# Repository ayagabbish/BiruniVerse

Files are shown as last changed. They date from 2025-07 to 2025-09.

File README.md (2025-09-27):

<h1 align="center">BiruniVerse Team</h1>
<p align="center">
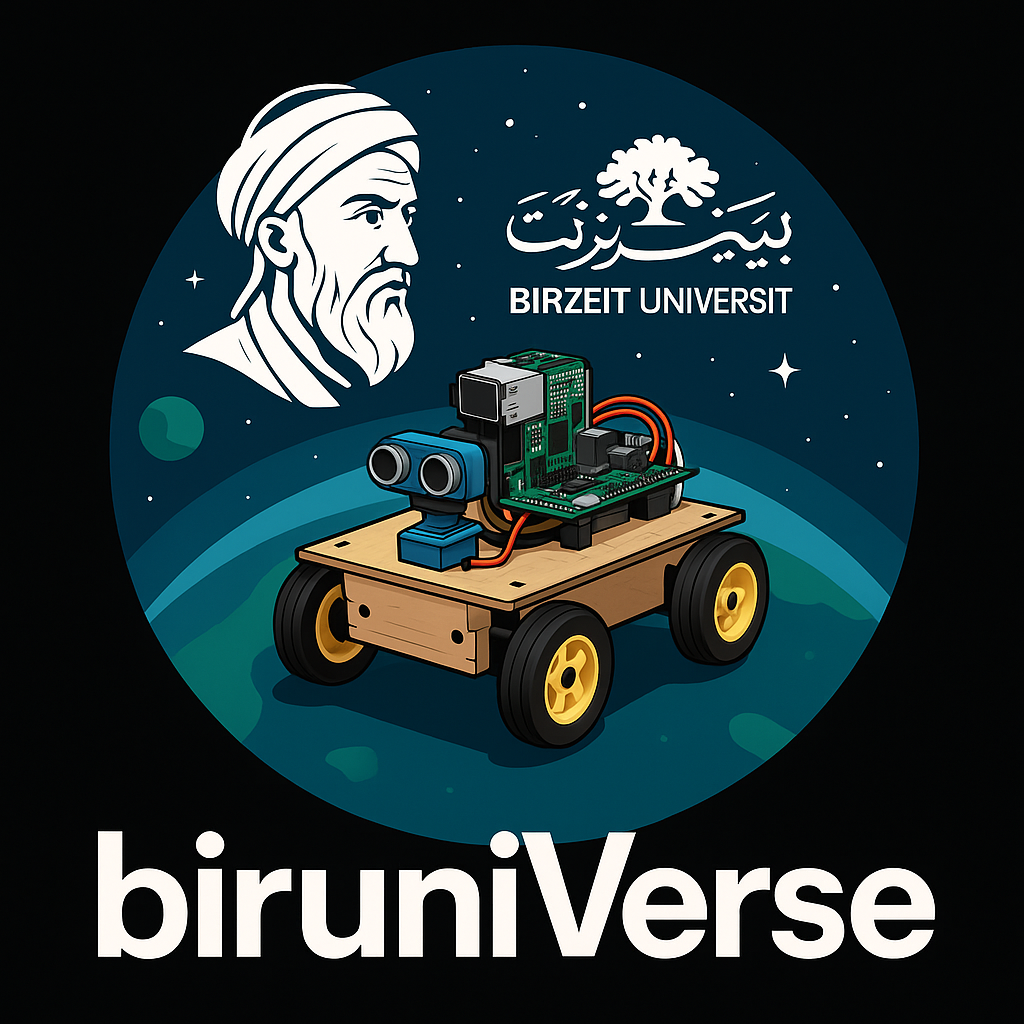
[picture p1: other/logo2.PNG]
BiruniVerse Logo
  

>  This repository documents the technical design, engineering processes, and development stages of our autonomous vehicle prototype. Built by three passionate engineering students, this robot is our gateway to the universe. United by creativity and curiosity, and supported by Birzeit University, we proudly present our journey in the WRO Future Engineers Challenge 2025.
## Content

* `t-photos` contains 2 photos of the team (an official one and one funny photo with all team members)
* `v-photos` contains 6 photos of the vehicle (from every side, from top and bottom)
* `video` contains the video.md file with the link to a video where driving demonstration exists
* `schemes` contains one or several schematic diagrams in form of JPEG, PNG or PDF of the electromechanical components illustrating all the elements (electronic components and motors) used in the vehicle and how they connect to each other.
* `src` contains code of control software for all components which were programmed to participate in the competition
* `models` is for the files for models used by 3D printers, laser cutting machines and CNC machines to produce the vehicle elements. If there is nothing to add to this location, the directory can be removed.
* `other` is for other files which can be used to understand how to prepare the vehicle for the competition. It may include documentation how to connect to a SBC/SBM and upload files there, datasets, hardware specifications, communication protocols descriptions etc. If there is nothing to add to this location, the directory can be removed.
# Table of Contents
- [Competition Overview](#competition-overview)
- [Who Are We?](#who-are-we)
- [Why BiruniVerse?](#why-biruniverse)
- [Understanding the Challenge](#understanding-the-challenge)
- [Robot Aims and Objectives](#robot-aims-and-objectives)
- [Hardware Design](#hardware-design)
  - [1. Chassis Plate](#1-chassis-plate)
  - [2. Wheels](#2-wheels)
    - [Front Wheels](#front-wheels)
    - [Rear Wheels](#rear-wheels)
  - [3. Steering Mechanism](#3-steering-mechanism)
  - [4. Gearbox](#4-gearbox)
  - [5. Controllers](#5controllers)
  - [6. Sensors](#6-sensors)
  - [7. Motors](#7-motors)
  - [8. Motor Drivers](#8-motor-drivers)
  - [9. Power](#9-power)
  - [10. Camera](#10-camera)
- [Strategies](#strategies)
  - [First Task: Navigation Without Traffic Signs](#first-task-navigation-without-traffic-signs)
  - [Second Task: Obstacle Avoidance](#second-task--obstacle-avoidance)
---

## Competition Overview

The World Robot Olympiad (WRO) challenges students to design and build autonomous robots.  
In the **Future Engineers** category, teams develop a self-driving car capable of navigating a randomized track using onboard sensors and control logic.  

The robot must be compact (**30 × 20 × 30 cm**) and operate fully without remote control.  
The goal is to replicate real-world autonomous driving, where the robot detects its environment, makes decisions, and completes laps reliably.  

Success is measured by both the robot’s performance on the track and the quality of the **engineering documentation** shared on GitHub, reflecting the full journey from design to competition-ready system.  

We chose to document our journey in the form of a story — step by step, from forming our team to building our final robot.  
Because in every line of code, every printed part, and every late-night fix, there is a story worth telling: a story of ideas turning into motion, and motion turning into achievement.  

##  Who Are We?

**spring 2025 – We came together.**  
Three students from different majors united with one goal: build a robot that goes beyond expectations.

-  **Alma Alkhader** – _Computer Engineer_  

-  **Aya Ghabbeish** – _Mechatronics Engineer_  

- **Sara Afifi** – _Mechanical Engineer_  

Together, we are **biruniVerse** — inspired by Birzeit and destined for the universe.

## Why BiruniVerse?

Our name **BiruniVerse** is built on two roots:  

- **Biruni** → A tribute to *Al-Biruni*, the great Muslim scholar and polymath, known for his groundbreaking contributions to science, astronomy, mathematics, and engineering. His curiosity and drive for discovery inspire us to push the limits of knowledge.  
- **Birzeituniversity (birUni)** → A proud reference to *Birzeit University*, our home, where this project was born. It connects our identity as students to a tradition of learning and innovation.  

The second part of our name, **Universe**, reflects our belief that through projects like these we are not only building robots — we are building the skills, imagination, and courage to reach for the universe itself.  

**BiruniVerse = Biruni + Birzeituni + Universe**  
A name that ties together heritage, identity, and aspiration.  

## Understanding the Challenge

Our journey began with the WRO 2025 Future Engineers rulebook, the document that defines every detail of the competition. Reading it gave us a clear picture of what the competition expected:  
a self-driving car that can complete laps on a randomized track, obey traffic rules with red and green pillars — all without human intervention.

After studying the rules, we joined training sessions at our university. There we met fellow participants, last year’s winners, coaches, and mentors. They encouraged us to ask questions, to experiment, and most importantly, to approach this as an engineering learning process, not just a race.

From there, we started exploring strategies and technical designs. We looked deeper into possible hardware parts that could be used, and we began asking specific questions to define our goals and shape our approach to solving the challenge.

##  Robot Aims and Objectives

- Detect obstacles using sensors and camera.  
- Avoid obstacles from the correct side.  
- Drive on its own without help.  
- Fix itself if it crashes or gets stuck.  
- Count laps and stop after finishing.  
- Stay inside size and hardware limits.

## Hardware Design

### 1. chassis Plate:

For the foundation of our robot, we chose a standard plastic chassis

<p align="center">
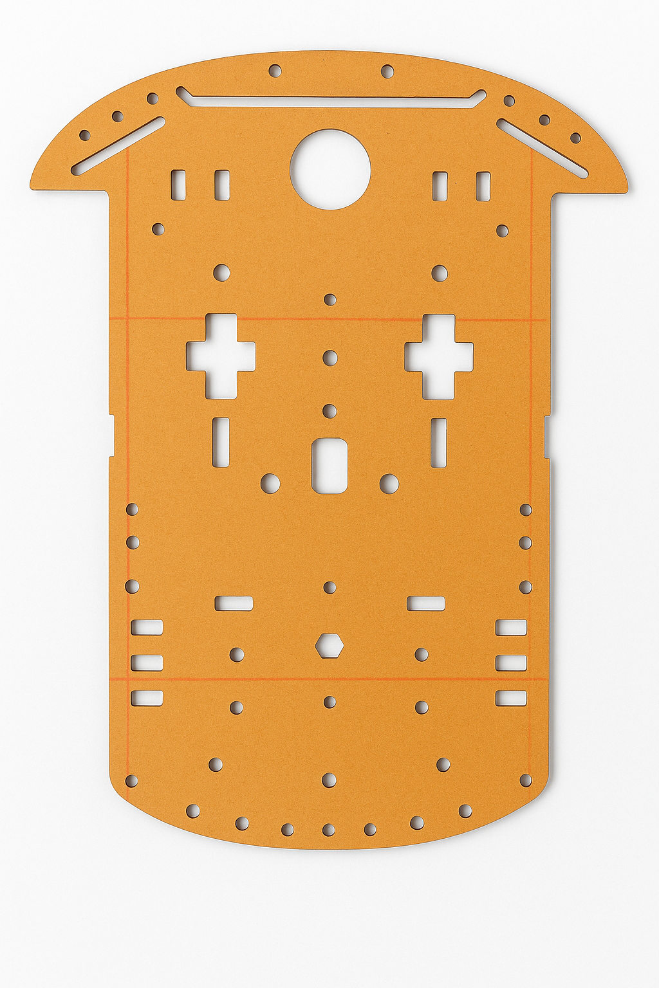
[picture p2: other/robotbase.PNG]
robotbase pic
  
</p>
The reason behind choosing this base was driven by simplicity and practicality, it offered a flat, stable surface with numerous mounting holes, which helped with arranging and securing components.

However, our structural requirements were not entirely satisfied by that base, so we had to modify it to fit our design by making new holes and gaps in the base to allow cleaner wire connection between the the upper controllers and the lower motors. Additionally, we made extra openings near the back to give the rear wheels enough clearance, and prevent them from hitting the base.

<p align="center">
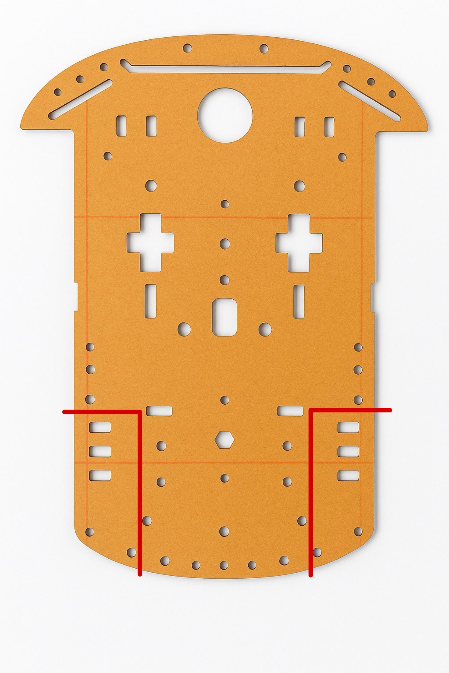
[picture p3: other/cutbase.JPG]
cutbase pic
  
</p>

This picture shows how the chassis was cut to fit the wheels properly.
for the cutting process, we used a **silverflo 928D tool soldering and cutting tool**, we relied on its heated tip and fine control to carefully shape the chassis.
<p align="center">
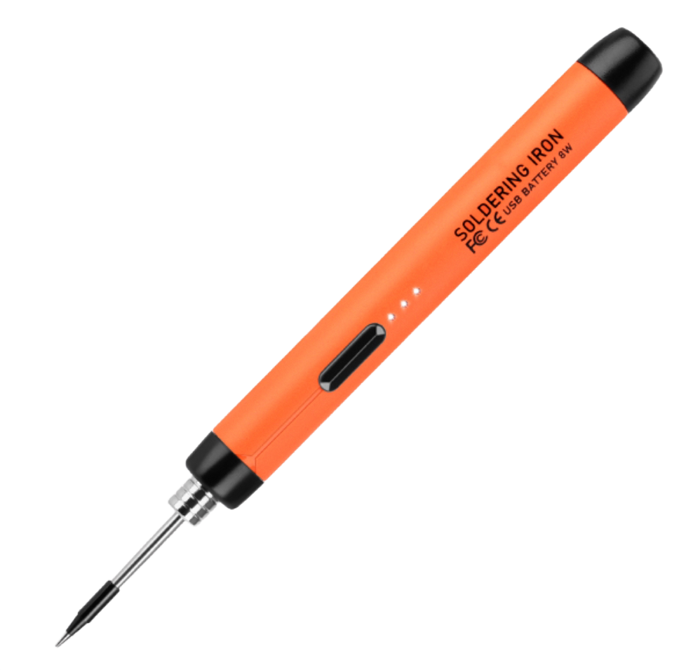
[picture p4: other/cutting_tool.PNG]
  
</p>

---

### 2. wheels:

#### Front Wheels

#### Starting Point – Store-Bought Wheels
We began with standard RC-style wheels that came with our chassis.  
These wheels consisted of:
- **Outer Tire**: black rubber with tread for grip.  
- **Plastic Hub**: inner white rim that holds the tire and connects to the axle.  

<p align="center">
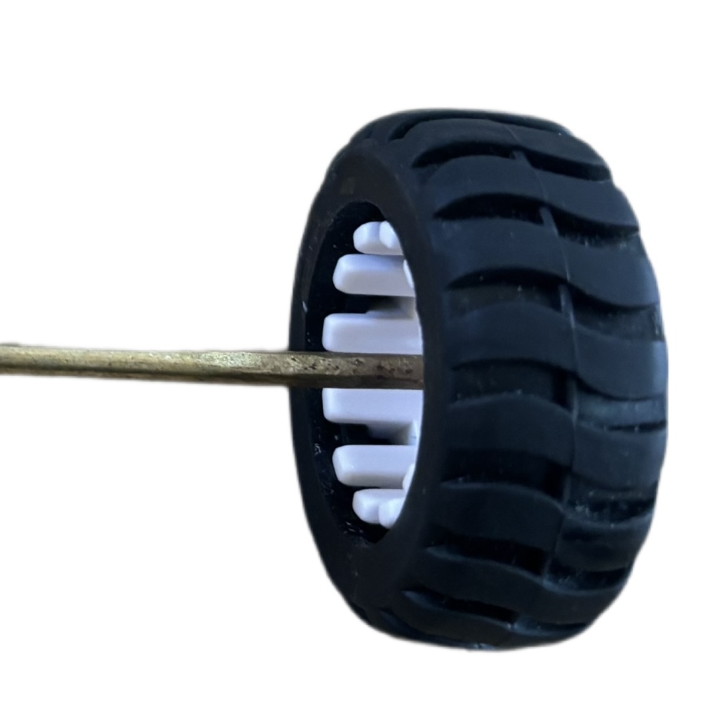
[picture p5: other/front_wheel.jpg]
frontwheelpic
  
</p>

#### Problem – Wobbling During Rotation
During testing, we noticed a **wobbling problem** in the wheels.  

The issue was caused by:
- Loose fit between the wheel hub and the axle.  
- Lack of a proper rotational support structure.  

This wobbling reduced **stability, steering precision, and vehicle speed**.
<p align="center">
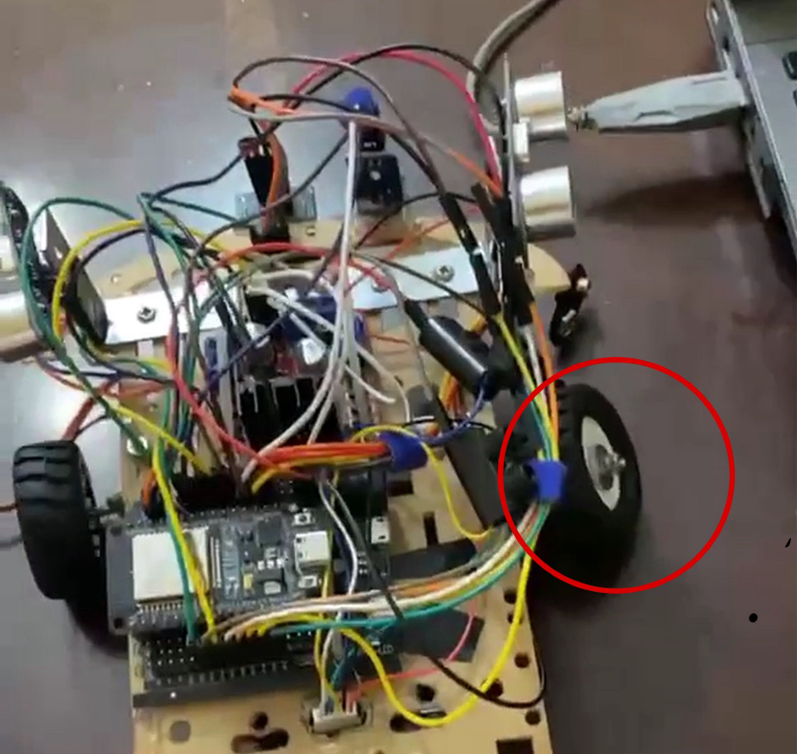
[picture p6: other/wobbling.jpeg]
wobblingwheelspic
  
</p>

#### Solution – Adding Bearings
To eliminate wobbling, we modified the wheels to include **ball bearings** (skateboard-style, model 608Z).

<p align="center">
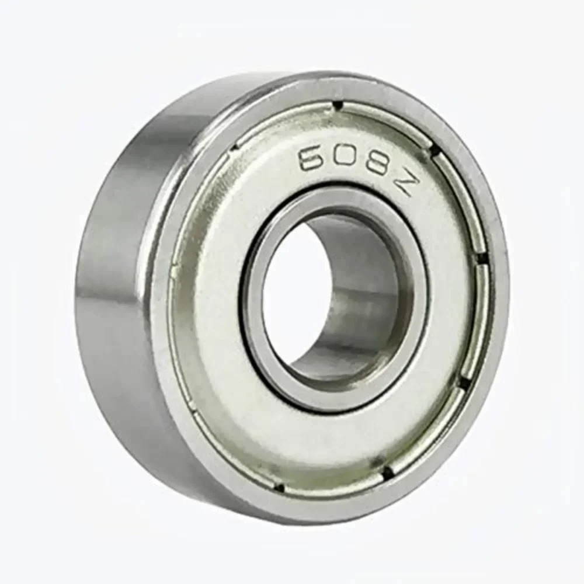
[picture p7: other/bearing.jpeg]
bearingspic
  
</p>

##### Why Bearings?
- Bearings allow the wheel to rotate smoothly around the axle.  
- They reduce friction, which increases efficiency.  
- They keep the wheel aligned and stable, preventing wobble.

### Front wheels assembly

1. **Outer Tire**  
   - Black part with tread made of rubber, providing grip on the track.  
   - Standard RC-style tire that slips over the wheel hub.  

2. **Wheel Hub (White Plastic Rim)**  
   - The inner white circular part that holds the tire.  
   - It was cut in some spots to fit the bearing.  

3. **Ball Bearing (608Z)**  
   - Standard skateboard/roller bearing.  
   - Allows the wheel to rotate smoothly around the axle with reduced friction.  

4. **Axle & Nuts Assembly**  
   - A metal threaded rod (axle) passes through the bearing.  
   - On the outside, nuts and washers fix the wheel in place to prevent wobbling.  
   - The threaded axle connects to the chassis, supported by mounts.
     
<p align="center">
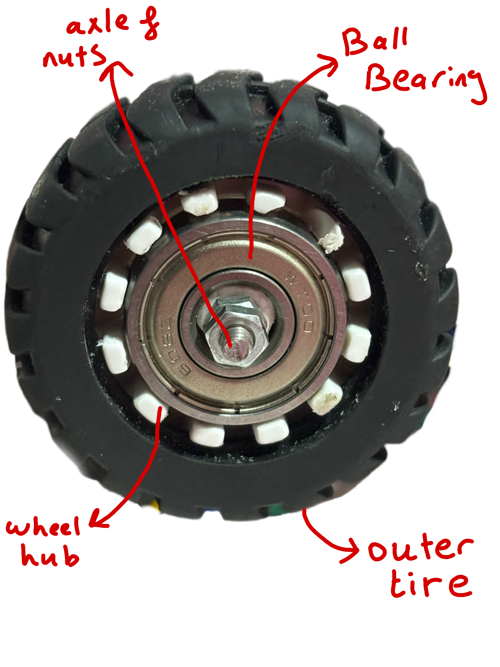
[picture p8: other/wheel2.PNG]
outsideviewoftires
  
</p>
*Outside view showing tire, hub, bearing, axle, and nuts.*  
<p align="center">
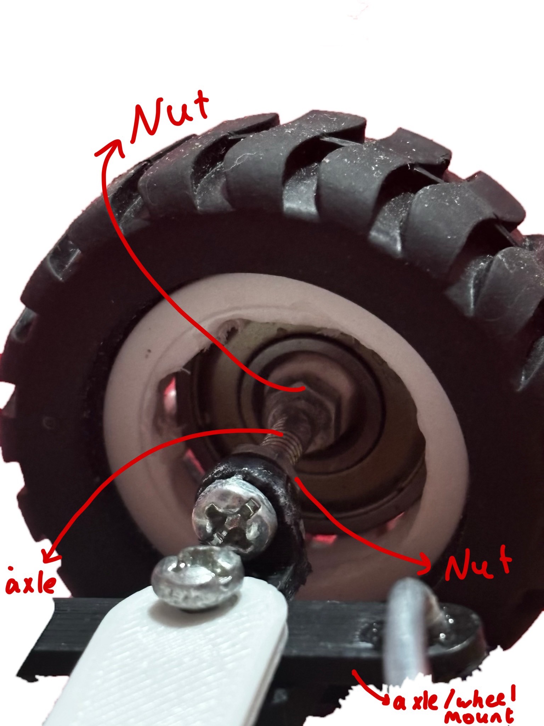
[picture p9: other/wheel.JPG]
insideviewoftires
  
</p>
*Inside view of the same assembly.*  

We used this same technique for **both front wheels**, ensuring stability and smooth steering.

---

#### Rear Wheels

For the rear wheels, we initially planned to use wheels similar to the front ones. However, after upgrading to a **stronger DC motor**, we faced an issue: the motor’s torque and size caused the motor to hit the ground.  

To solve this, we switched to **larger rear wheels**:  

<p align="center">
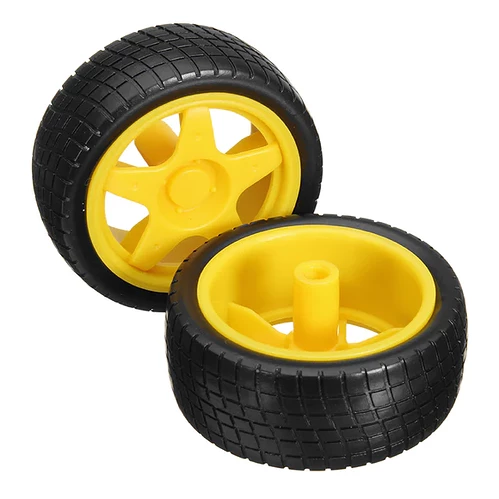
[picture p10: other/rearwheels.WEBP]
Rear Wheels
  
</p>  

our inspiration for Small Front wheels + Large Rear came from **Tractors**: 
This setup mimics heavy machinery like **Tractors**, which use **smaller front wheels** and **larger rear wheels**:  
- The **smaller front wheels** make steering easier and more precise.  
- The **larger rear wheels** provide the **power and stability**, supporting the motor’s torque and carrying most of the load.
  
  <p align="center">
  Rear Wheels
</p>  

---

### 3. Steering Mechanism:
for our steering meachanism we followed the idea in this video: https://youtu.be/ZdtPTUsrAA4?si=SmZMQu09OpZvmOV_

We decided to recreate the steering parts using SoliWorks, so we could 3D print them with strong plastic for durability.

Our robot uses a servo-based steering system inspired by real car steering (Ackermann principle). The mechanism ensures both front wheels turn together when the servo moves.

####  steering system components

| Name | Explanation | Picture |
|---|---|---|
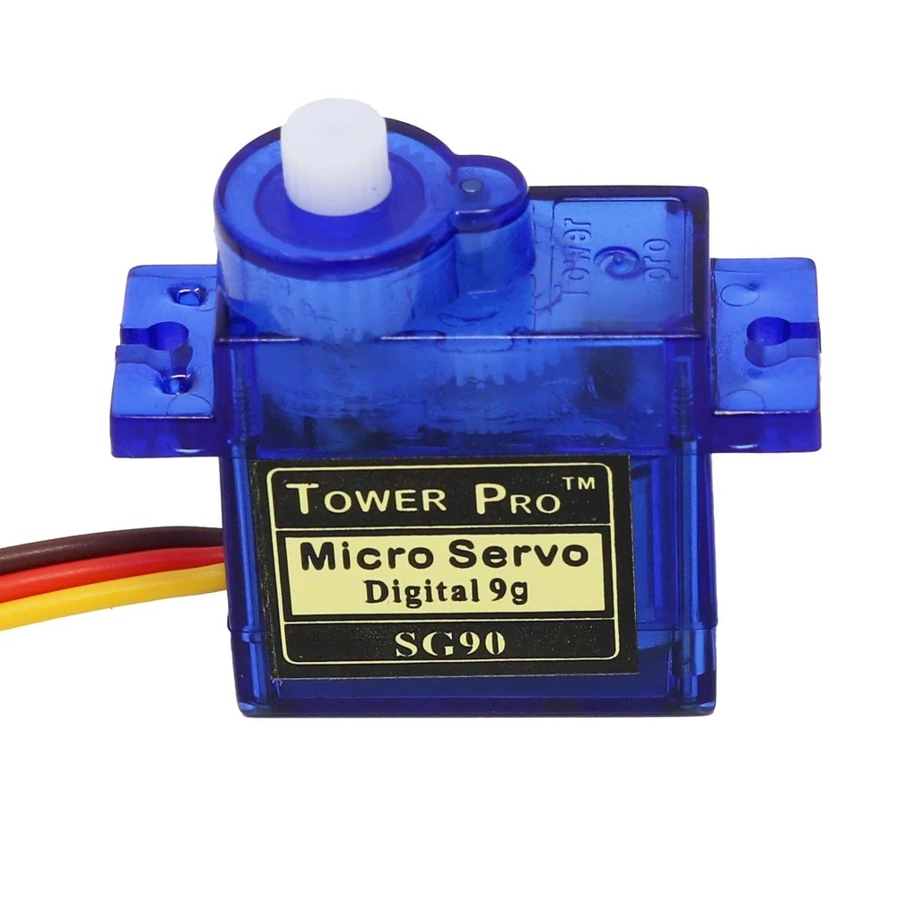
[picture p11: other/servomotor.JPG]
| **Servo Motor** | **Purpose:** The actuator that initiates steering. <br> **How it works:** The servo rotates a precise angle (controlled by the ESP32). |   |
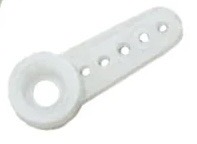
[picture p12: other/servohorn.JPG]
| **Servo Horn** | **Purpose:** The white plastic arm attached to the servo shaft. <br> **How it works:** When the servo rotates, the horn converts that into a small push–pull motion at its tip. <br> **Why needed:** Provides a lever arm so the servo’s rotation can be transferred into linear motion for the linkage rod. | |
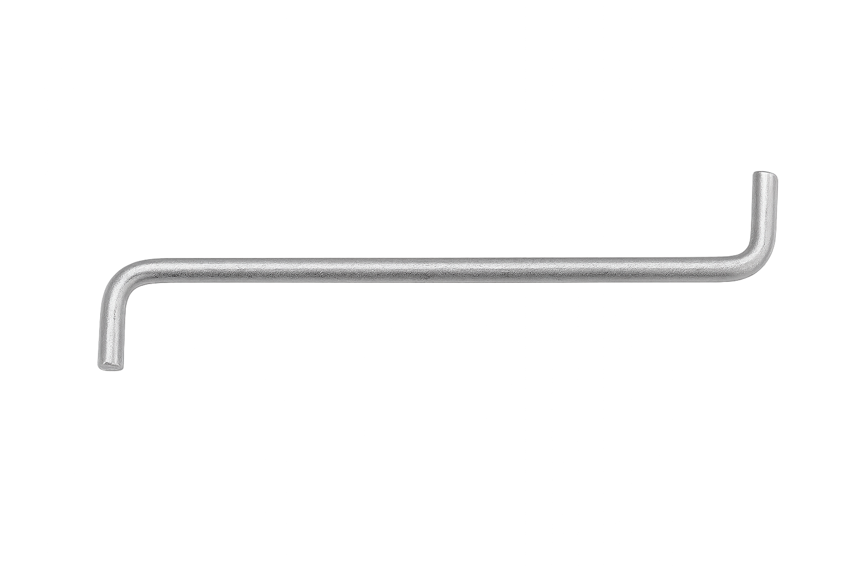
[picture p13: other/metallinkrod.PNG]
| **Metal Link Rod**  | **Purpose:** Connects the servo horn to the first steering knuckle. <br> **How it works:** Moves back and forth as the horn rotates, converting the servo’s rotation into reciprocating linear motion. <br> **Why needed:** Acts as the bridge between the servo and the steering system. Without it, the servo could not move the knuckle. |   |
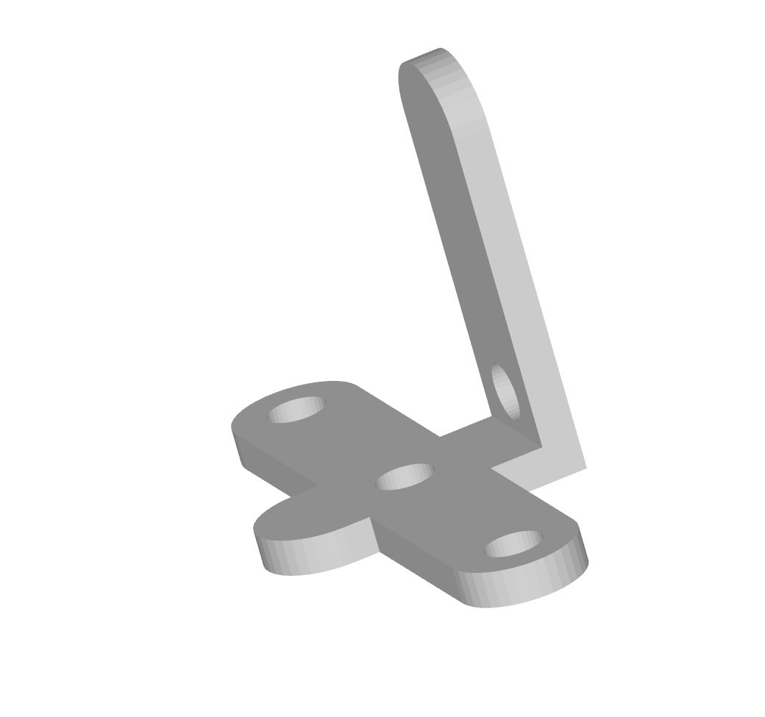
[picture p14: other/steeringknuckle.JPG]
| **Steering Knuckle**| **Purpose:** Holds the wheel axle and connects to both the linkage rod and the tie rod. <br> **How it works:** It pivots around a vertical screw fixed to the chassis. When the linkage rod pushes/pulls, the knuckle rotates, turning the wheel axle left or right. <br> **Why needed:** Essential for steering — it allows the wheel to turn while still being free to spin for forward/backward motion. |  |
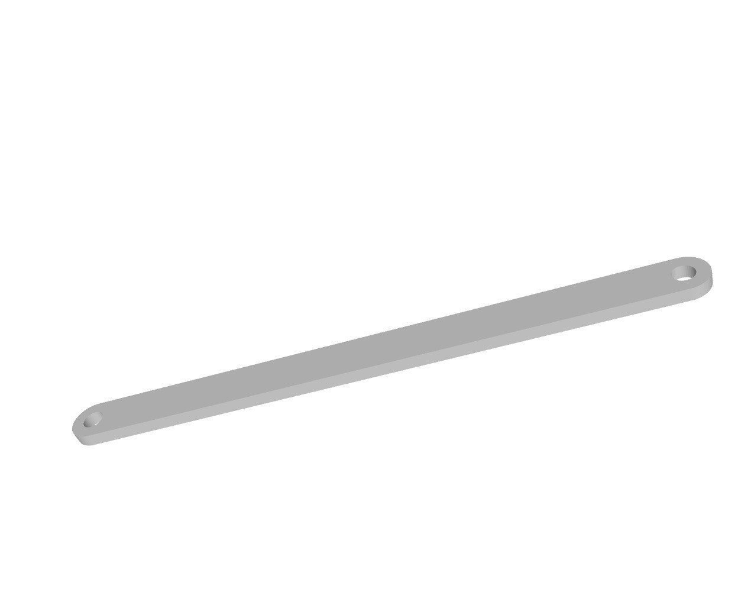
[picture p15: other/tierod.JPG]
| **Tie Rod** | **Purpose:** Connects the first steering knuckle to the second steering knuckle. <br> **How it works:** When the first knuckle pivots, the tie rod pushes or pulls the second knuckle so that both wheels turn together. <br> **Why needed:** Without it, only one wheel would steer, causing uneven turning and drag. The tie rod ensures synchronized steering. | |
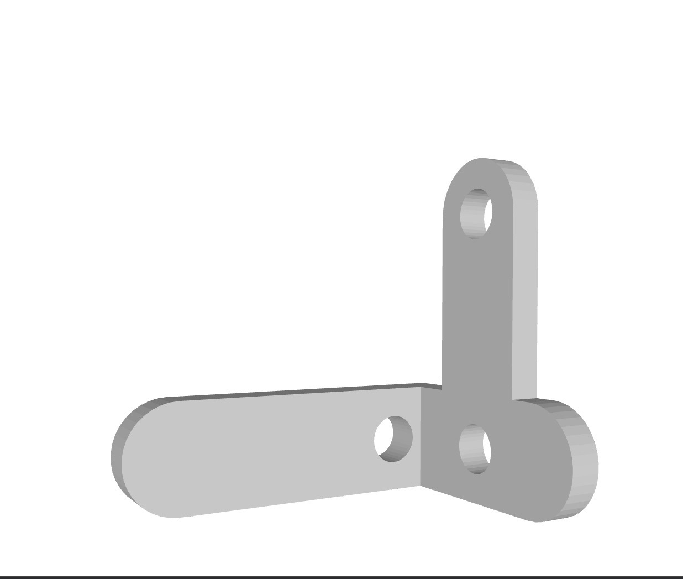
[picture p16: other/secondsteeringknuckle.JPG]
| **Second Knuckle**  | **Purpose:** Mirrors the motion of the first knuckle through the tie rod. <br> **How it works:** Pivots when pulled/pushed by the tie rod, turning the second wheel. <br> **Why needed:** Ensures the second wheel turns in harmony with the first, giving stable and accurate steering. | |
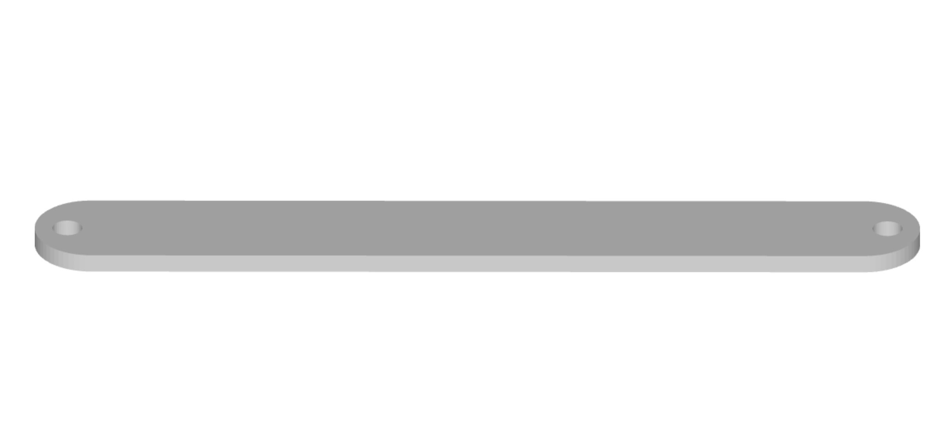
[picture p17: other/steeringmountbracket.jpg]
| **Steering Mount Bracket (x2)** | **Purpose:** Connects the steering knuckle to the chassis with a vertical screw. <br> **How it works:** Acts as the pivot base for the knuckle. <br> **Why needed:** Keeps the knuckle rigidly fixed in place, allows free pivoting around the screw without wobbling. |   |
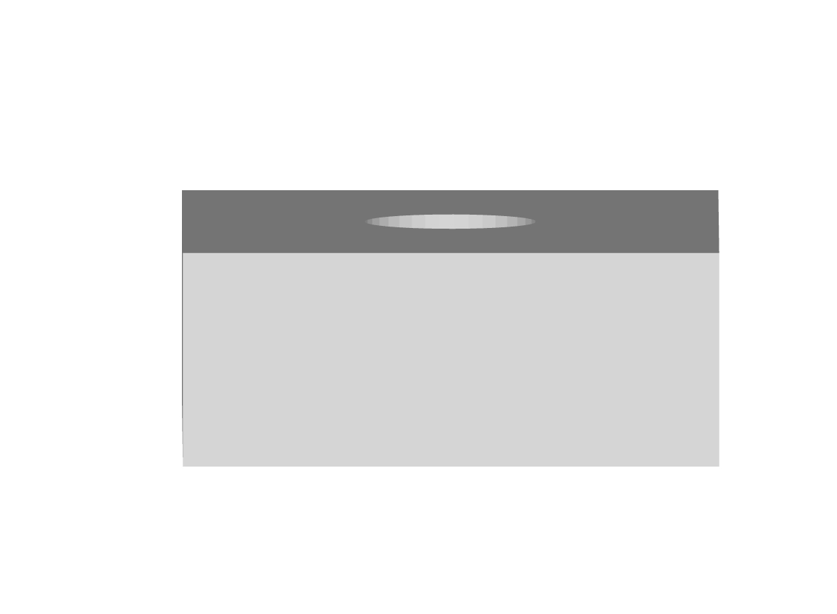
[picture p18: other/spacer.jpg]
| **Spacer Block (x2)** | **Purpose:** Provides the required vertical clearance between the mount bracket and the knuckle. <br> **How it works:** Sits between the mount bracket and the steering knuckle; the screw passes through it. <br> **Why needed:** Prevents the knuckle from rubbing against the mount bracket. Aligns the linkage rod and tie rod at the correct height for smooth steering geometry. |  |

---

### 4. Gearbox:

For our drivetrain, we built a **simple right-angle gearbox**. 
Before designing our own gearbox, we studied gears from a toy car.  
The images below show the original toy car gears and their measurements, which served as inspiration for our custom build, which we then adjusted its measurements to match our motor and build needs.

These are the toy car gears we used as inspiration for our gearbox design:

| | | |
|---|---|---|
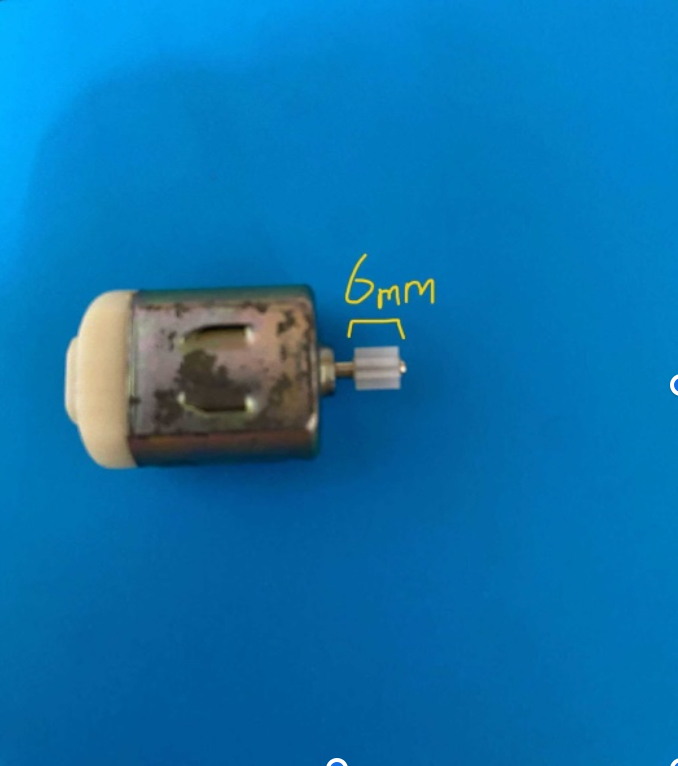
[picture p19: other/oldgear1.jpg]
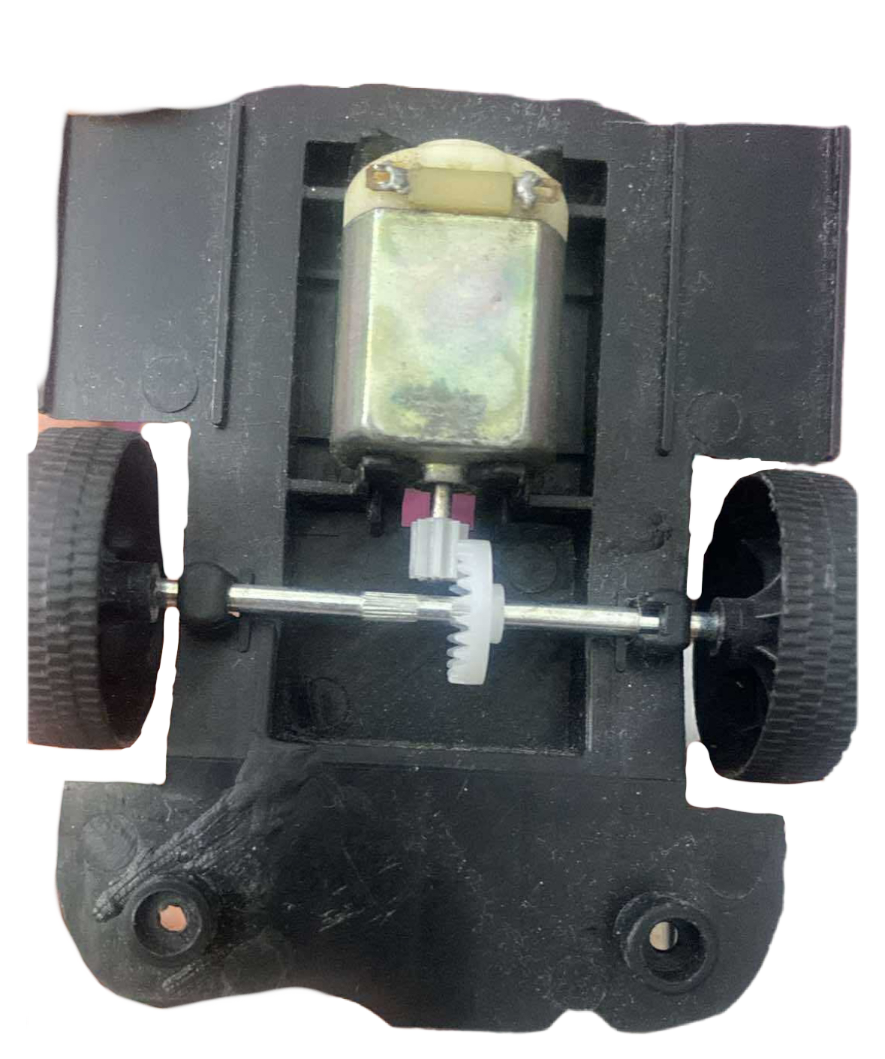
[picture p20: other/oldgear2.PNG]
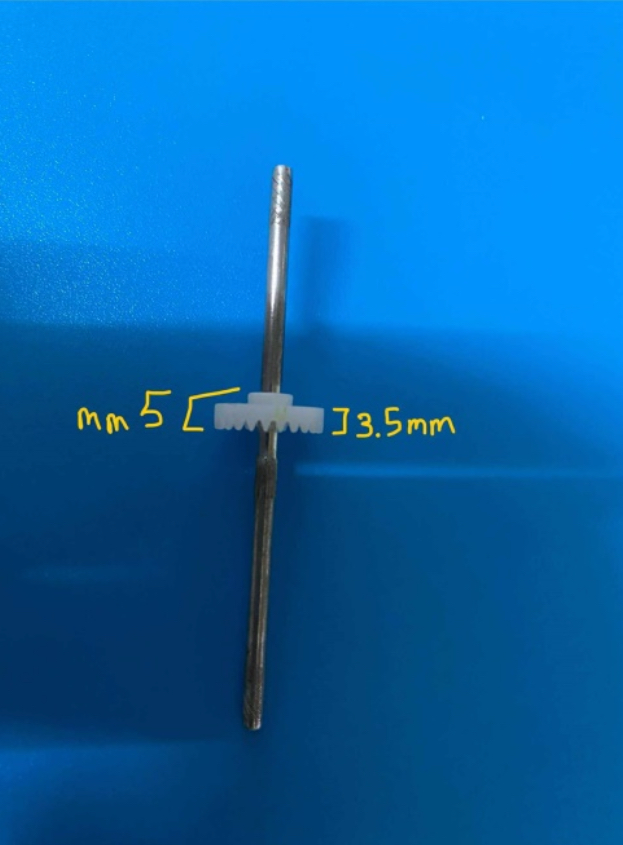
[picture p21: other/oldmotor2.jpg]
|  | |  |

#### Small Gear Component
- Length: **6 mm**  
- Gear teeth thickness: **3.2 mm** (but we required a larger outer diameter)  
- Motor mount diameter: **~3 mm** → the gear was hollowed out to fit this inner diameter.  
- Teeth count: **8 teeth**  
- Larger gear: **24 teeth**  
- Ratio: **1:3**  
- Special feature: the motor shaft is **D-shaped**, so the gear’s inner hole was designed with a matching **D-shaped cut** (not circular) to fit securely.

<p align="center">
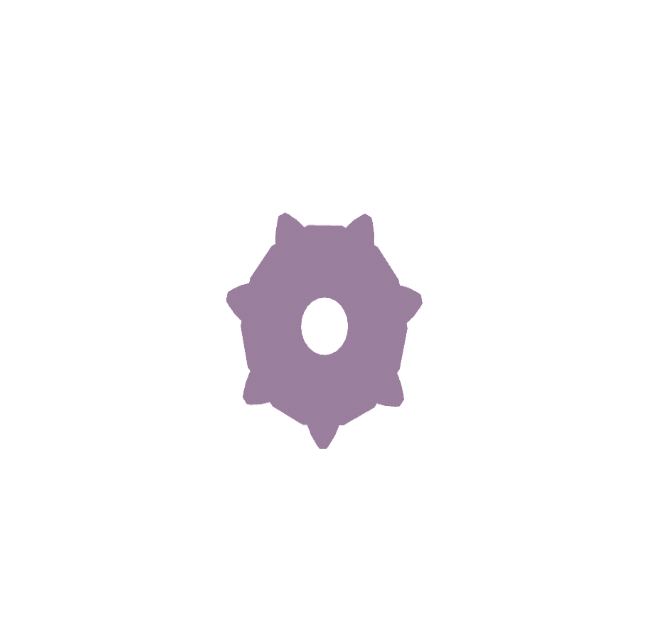
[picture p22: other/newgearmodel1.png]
  
</p>

#### Large Gear Component
- Teeth count: **24 teeth**  
- Pitch diameter: **7.2 mm** (original design)  
- Outer diameter: **≤ 10 mm**  
- Inner hole: **3 mm circular cutout** (for mounting)  
- Thickness: *(as per final design — adjusted for stability)*

<p align="center">
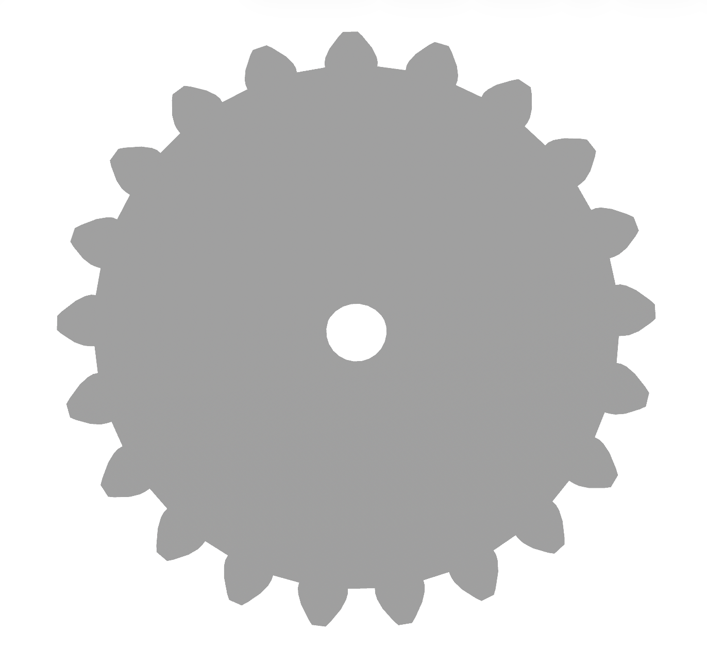
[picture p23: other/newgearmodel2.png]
  
</p>

final setup :
<p align="center">
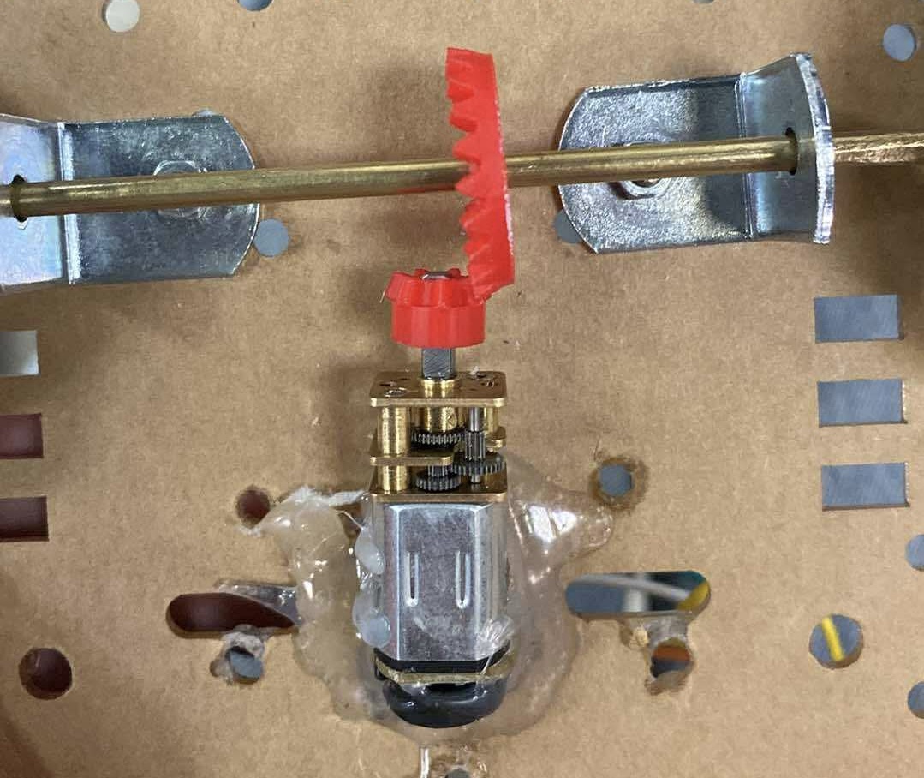
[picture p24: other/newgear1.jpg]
  
</p>
These picture were taken before replacing the DC motor.
These specifications guided the CAD modeling of the gears and ensured they were compatible with both our motor shaft and the required torque transfer for the robot.

---

### 5.controllers

The microcontroller is the **brain of the robot**, so our main priority was choosing the best one to do the job while also being cost-effective.

- Our first option was the **Arduino Nano 33 BLE Sense Rev2**, which supports machine learning models and is affordable.  
  However, we couldn’t find it locally in Palestine, so we decided to replace it with a **Raspberry Pi**.

- When comparing Raspberry Pi versions, we eliminated the 5th version because of **power limitations**.  
  The 4th version had better internet resources, making it easier to learn, but introduced new challenges:  
  the motors and sensors required different voltages than the Raspberry Pi. Using multiple voltage regulators seemed risky.

- To solve this, we decided on a **hybrid approach**:  
  - Use an **ESP32** connected to the **H-bridge** to handle motors and sensors, ensuring stable voltage regulation.  
  - Use the **Raspberry Pi 4** exclusively for **object detection**, reducing its workload and improving efficiency.

This combination allowed us to balance cost, availability, and performance while ensuring smooth operation of both control and perception tasks.

#### Raspberry Pi 4
<p align="center">
  Raspberry Pi 4
</p>

- **Processor**: 1.5GHz 64-bit quad-core  
- **RAM**: 8GB LPDDR4  
- **SD card**: 32GB 
- **Ports**: 2 USB 3.0 ports, 2 USB 2.0 ports
- **Operation Voltage** : 5.1V at 3A
- **Dimensions** : 85mm x 56mm x 17mm
- **Connectivity**:  
  - Dual-band Wi-Fi  
  - Bluetooth 5.0  
  - Gigabit Ethernet  
  - USB 3.0

***Purpose*** : The purpose of using the Raspberry Pi 4 was to connect a camera that provides visual input to the system. This input is then processed using machine learning, including image classification and recognition. Moreover, these methods guide the robot car to determine the turning direction based on live information and observations. In addition, the system can make decisions on the spot in a changing environment.

***Selection reason*** : As for the reason for choosing the Raspberry Pi 4, it is due to its easier-to-provide power source and lower power consumption. It is also more compatible when coding and using libraries. and lastly, its accessories are more affordable, and it generates less heat compared to the Raspberry Pi 5.

#### ESP32
<p align="center">
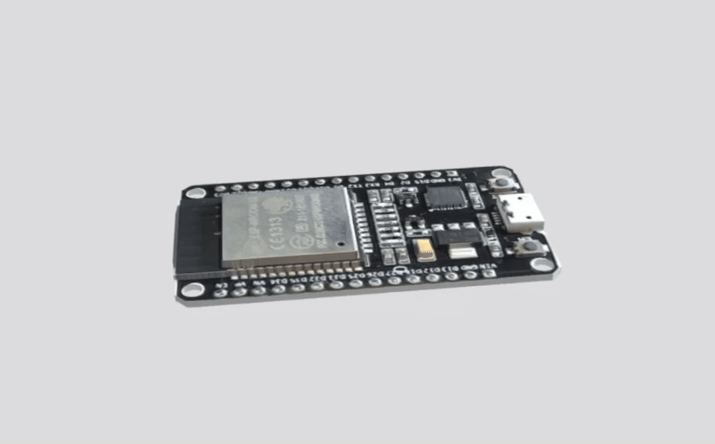
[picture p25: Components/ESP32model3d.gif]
Raspberry Pi 4
  
</p>

***Purpose*** : its to connect the rest of the robots components, sensors and motors, to ensure their best performance, we programmed the microcontroller using C++, It connects to the Raspberry Pi, which handles image recognition. Based on camera input (red or green obstacle), the Raspberry Pi sends commands to the ESP32, which then executes movement based on the code the esp32 runs, through the connected hardware.

***Selection reason*** : The ESP32 has many captivating and suitable features for our project, it has processing power of Dual-core 32-bit Xtensa CPU, up to 240 MHz, it has both Wi-Fi and Bluetooth (Classic + BLE) built-in, enough memory (520KB) to handle our code and execute it smoothly, has PWM On most GPIOs, its more cost effective, and it has more advanced features.

#### ESP32 Expansion Board
<p align="center">
<picture>
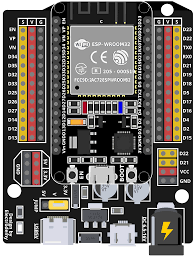
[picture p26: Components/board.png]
ESP32 Expansion Board
  
</picture>
</p>

- **Microcontroller**: ESP32 (dual-core, 240 MHz)  
- **Connectivity**: Wi-Fi + Bluetooth  
- **Operating Voltage**: 3.3V  
- **Programming**: Arduino IDE or MicroPython  
- **USB**: For power and programming (usually Micro-USB)  

***Purpose*** : Acts as the main controller for connecting sensors, processing inputs, and controlling outputs such as LEDs and motors.  

***Selection reason*** : Supports wireless communication, IoT applications, and runs code directly (Arduino/MicroPython). Flexible, powerful, and easy to integrate.  

---

---
### 6. sensors
#### Ultrasonic Sensor
<p align="center">
<picture>
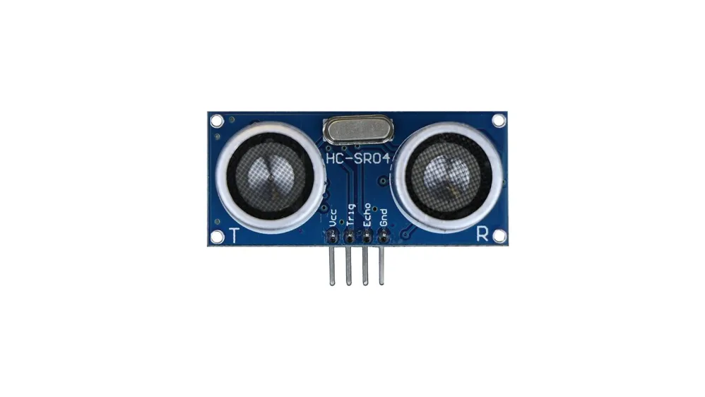
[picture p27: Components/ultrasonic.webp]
Ultrasonic Sensor
  
</picture>
</p>

**Model**: HC-SR04
**Voltage:** 5V DC  
**Current:** 15mA  
**Frequency:** 40Hz  
**Max Range:** 4m  
**Min Range:** 2cm  
**Measuring Angle:** 15°  
**Trigger Input:** 10µs TTL pulse  
**Echo Output:** TTL level signal (range proportional)  
**Dimensions:** 45 × 20 × 15 mm  

***Purpose*** : We have adopted a strategy that requires three ultrasonic sensors to be used effectively. Two sensors are placed on the sides, while the third is positioned at the front of the car. The side sensors are responsible for measuring the distance between the car and the walls on each side of the path. They continuously compare the two readings to determine the car’s position. When one of the side sensors detects a distance greater than the other by more than 2 meters, the system will determine that side as the turning direction of the path. As for the third sensor at the front, its main purpose is to measure the distance between the car and any obstacles, which will later be used to decide when the car should start turning at an angle to avoid collisions. It will also measure the distance between the walls of the track and the car, which will be useful—combined with our servomotor and camera in Task 2.

#### Infrared Sensor
<p align="center">
<picture>
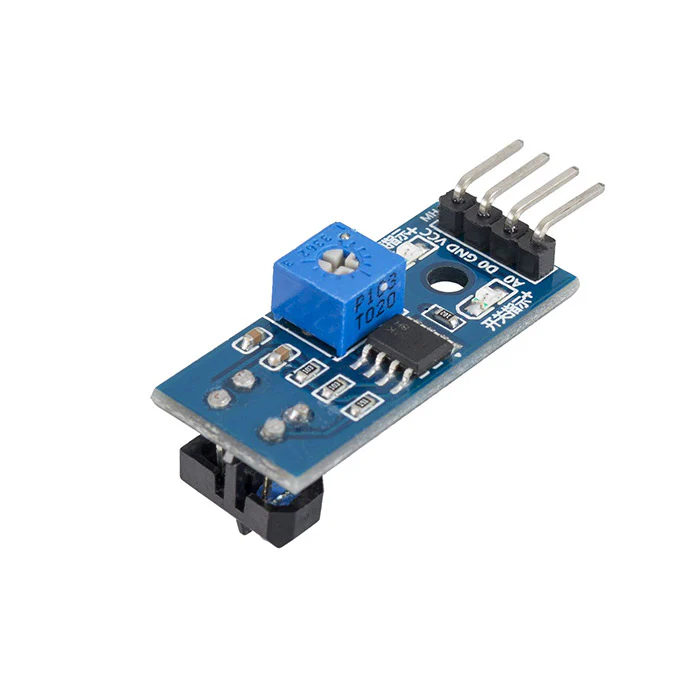
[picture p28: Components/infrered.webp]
Infrared Sensor
  
</picture>
</p>

- **Model**: TCRT5000  
- **Operating Voltage**: 3.3V – 5V  
- **Current Consumption**: ~18–20 mA  
- **Detection Range**: 2 mm – 15 mm (optimal within 2–10 mm)  
- **Output Signal**: Digital (HIGH/LOW) or Analog (depending on board version)  
- **Detection Type**: Reflective infrared (IR LED + phototransistor)  
- **Wavelength**: ~950 nm (IR emitter)  
- **Response Time**: <1 ms (fast switching)  
- **Adjustable Sensitivity**: Yes (via onboard potentiometer, if available)  
- **Indicator LEDs**: Power and output status  
- **Dimensions (module)**: ~3.2 cm × 1.4 cm (can vary by version)  

***Purpose*** : The purpose of this sensor is to detect short distances between the robot and its surroundings. While it may seem similar to the ultrasonic sensor, its main role is to provide an extra layer of safety to prevent collisions with obstacles or walls. It also helps the robot determine when to move backwards if needed.  

***Selection reason*** : It senses short distances more precisely than the ultrasonic sensor.  

#### Color Sensor
<p align="center">
<picture>
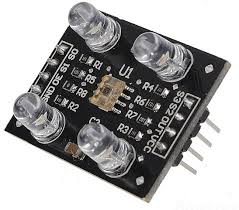
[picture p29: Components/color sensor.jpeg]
Color Sensor
  
</picture>
</p>

- **Model**: TCS3200 Color Sensor  
- **Operating Voltage**: 2.7V – 5.5V (typically 5V)  
- **Operating Current**: ~2.5 mA (average)  
- **Output Type**: Frequency (square wave) proportional to light intensity  
- **Sensing Element**: 8×8 array (64 photodiodes):  
  - 16 red filters  
  - 16 green filters  
  - 16 blue filters  
  - 16 clear (no filter)  
- **Selectable Output Frequency Scaling**: 100%, 20%, and 2%  
- **Measurement Range**: Full visible spectrum (RGB + clear)  
- **Response Time**: <100 ms typical  
- **Interface**: Digital output (no ADC needed)  
- **Detection Method**: Measures reflected light intensity of different colors  
- **Module Dimensions**: ~28 mm × 28 mm (may vary by version)  

***Purpose*** : Its main job is to detect either a green or orange line on the mat, which is used to count how many laps the robot car has completed. If it detects 12 orange lines, it means the car has finished 3 laps and should park (the mat has 4 orange lines at each corner, so 4 lines equal one lap). The color sensor also had another role in a different strategy: to determine the direction of the car (clockwise or counterclockwise). This was based on the color of the first line detected, which guided the system to track that color and decide turning direction, which was our initial stratege for counting laps before switching to a strategy that relies on sata from ultrasonic seneors.

***Selection reason*** : Provides reliable detection of specific colors, enabling lap counting and alternative navigation strategies.  

---

### 7. Motors:
#### Servo Motor
<p align="center">
<picture>
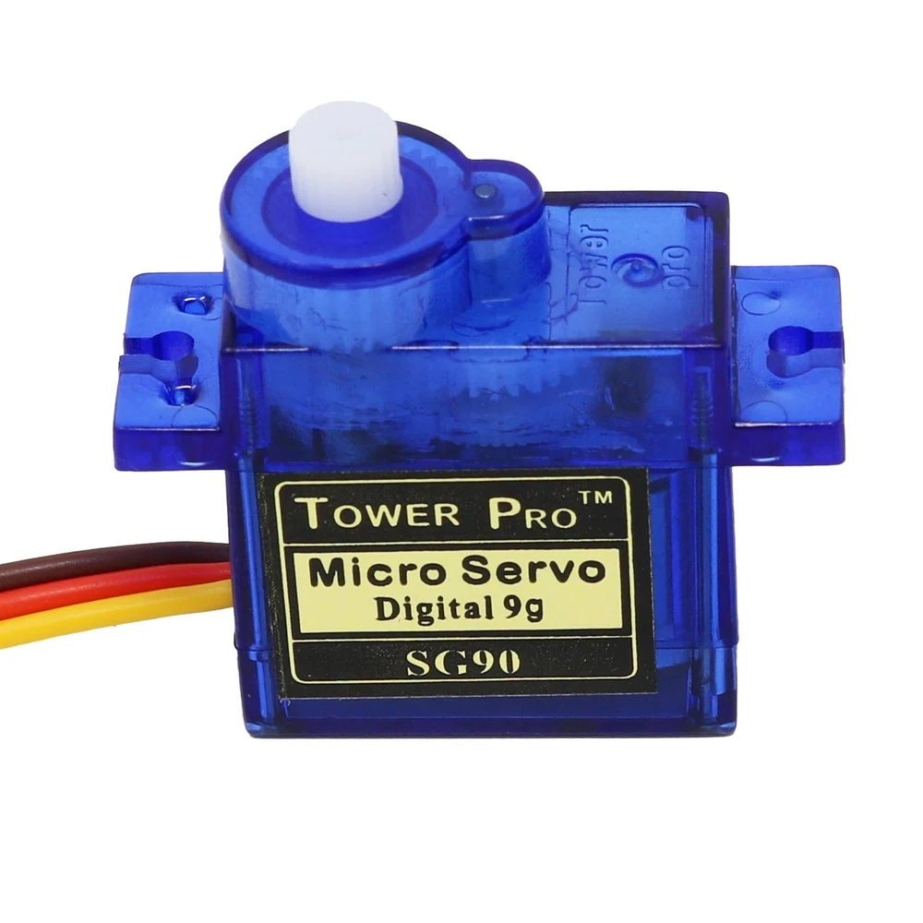
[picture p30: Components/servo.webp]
Servo Motor
  
</picture>
</p>

- **Model**:DCGM-N20-12V-EN-200RPM
- **Voltage**: 4.8V to 6V  
- **Operating Current**: ~100 mA to 250 mA (under load)  
- **Stall Torque**: 1.8 kg·cm at 4.8V  
- **Speed**: ~0.1 sec/60° at 4.8V  
- **Rotation Range**: 0° to ~180° (limited by internal stops)  
- **Control Signal**: PWM (50 Hz, 1–2 ms pulse width)  
- **Motor Type**: Brushed DC motor with control circuitry and feedback  
- **Weight**: ~9 g  
- **Dimensions**: 22.8 × 12.2 × 29.5 mm  
- **Gear Type**: Plastic gears  
- **Shaft Type**: Spline (21 teeth)  
- **Connector**: 3-pin (Signal, VCC, GND)  

***Purpose*** : Used in the robot car’s steering mechanism. In Task 2, it worked with the camera and Teachable Machine to avoid obstacles dynamically by adjusting angles gradually. In Task 1, it turned 90° at track edges with ultrasonic input to keep the car aligned.  

***Selection reason*** : Compact, affordable, easy to control, and accurate for 0°–180° rotation, making it ideal for steering.
#### DC Motor (JGA25-370)
<p align="center">
<picture>
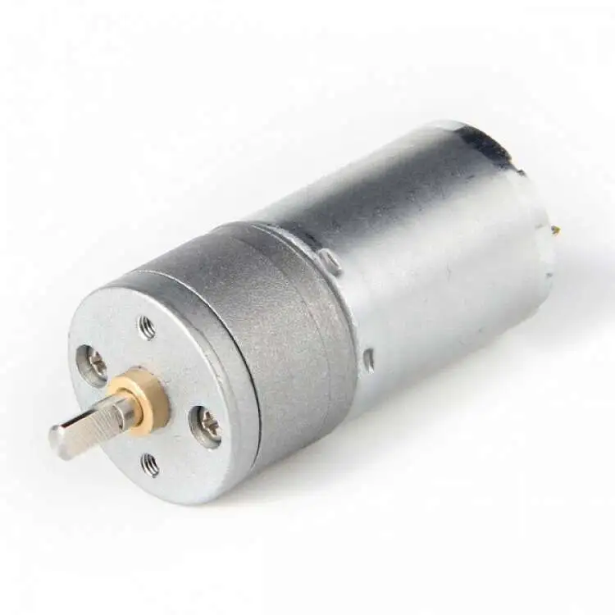
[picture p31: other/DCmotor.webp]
Servo Motor
  
</picture>
</p>

- **Model:** JGA25-370 DC Gear Motor  
- **Rated Voltage:** 6–12 V DC  
- **No-load Speed:** ~30–600 RPM (varies by gear ratio & supply voltage)  
- **No-load Current:** 70–150 mA  
- **Stall Torque:** 2–20 kg·cm (depending on gear ratio)  
- **Stall Current:** 1.5–2.5 A  
- **Gearbox:** 25 mm diameter, all-metal reduction gearbox  
- **Shaft Diameter:** 4 mm D-shaped output shaft  
- **Motor Type:** Brushed DC motor with integrated gearbox  
- **Rotation:** Reversible (via polarity swap)  
- **Dimensions:** ~25 mm (diameter) × 55–70 mm (length, depends on gear ratio)  
- **Mounting:** M3 threaded holes on gearbox face  

**Purpose**  
This motor is the muscle of our self-driving robot. With its built-in gearbox, it delivers the torque needed to move the car smoothly around the WRO track, even when friction or obstacles add resistance. Its cylindrical shape makes it easy to mount on a custom chassis without taking too much space.

**Selection Reason**  
We chose the JGA25-370 because it represents a balance between **strength and compactness**. Unlike the smaller XY-N20 motors, which are great for precision but limited in torque, this motor provides the raw pushing power we need for reliable forward motion and acceleration. With multiple gear ratio options, it allows us to tune for either **speed** or **endurance**, depending on the strategy. In short: this is the powerhouse that keeps our vehicle in motion.

### 8. Motor Drivers:

#### H-Bridge
<p align="center">
<picture>
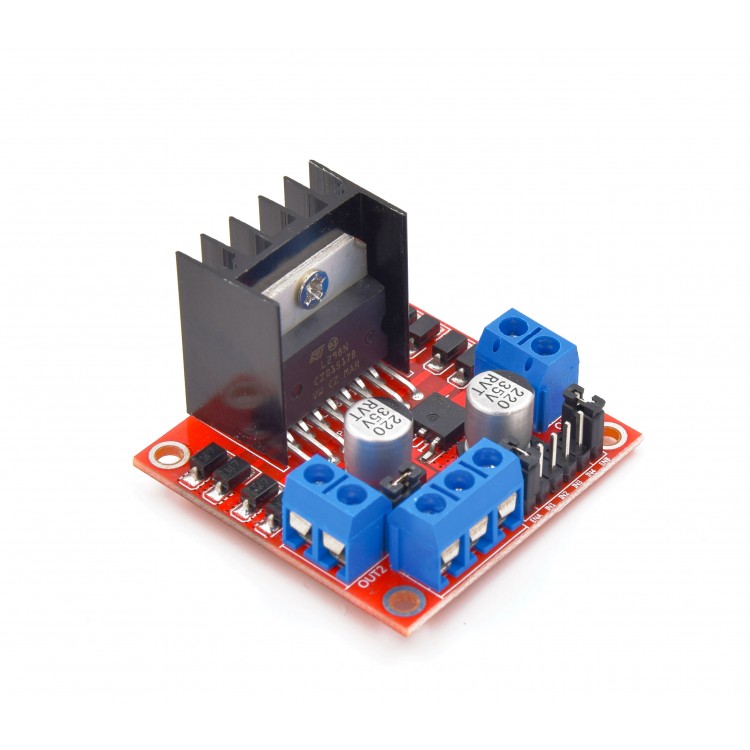
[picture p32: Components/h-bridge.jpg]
H-Bridge
  
</picture>
</p>

- **Voltage**: 5V to 35V  
- **Logic Voltage**: 5V  
- **Continuous Current**: 2A per channel  
- **Peak Current**: 3A per chann
- **Channels**: 2 (dual H-Bridge)  
- **Speed Control**: PWM (ENA/ENB pins)  
- **Direction Control**: IN1, IN2, IN3, IN4  
- **Protection**: Thermal shutdown, current limiting  
- **Flyback Diodes**: Included  

***Purpose*** : The ESP32 cannot directly reverse motor direction, but an H-Bridge enables this through simple digital HIGH/LOW signals. It also supports braking and freewheeling modes, offering finer control. It acts as a power driver, handling higher motor currents safely.  

***Selection reason*** : Without an H-Bridge, a DC motor can only spin one way. The H-Bridge makes motor control safe, programmable, and reliable.  
 
- **Model**: ESP32-WROOM-32 
- **Board**: NodeMCU-ESP32 (ESP32 DEVKITV1)  
- **Chip**: ESP32 (Dual-core Xtensa LX6, up to 240MHz)  
- **Wi-Fi**: 802.11 b/g/n (2.4GHz)  
- **Bluetooth**: v4.2 BR/EDR + BLE  
- **RAM**: 520KB SRAM  
- **Flash**: 4MB (or 16MB, depending on variant)  
- **GPIO Pins**: 38 (including ADC, DAC, UART, SPI, I2C)  
- **USB**: Micro-USB (for power/programming)  
- **Operating Voltage**: 3.3V
- **Dimensions** : 18mm x 25.5mm x 3.1mm

---

### 9. Power:

Our robot uses two different power sources to separate the load between the control electronics and the computing unit:

1. **9V Rechargeable Li-ion Battery (6600mAh)**
   - **Purpose:** Powers the **H-Bridge motor driver** and the **ESP32 microcontroller**.  
   - **Reasoning:** The ESP32 and H-Bridge require stable DC input for motor control and logic-level operations.  
   - **Advantage:** Keeps the motor driving system and the low-power controller on a dedicated supply, avoiding interference from the Raspberry Pi’s higher power draw.  
 <p align="center">
<picture>
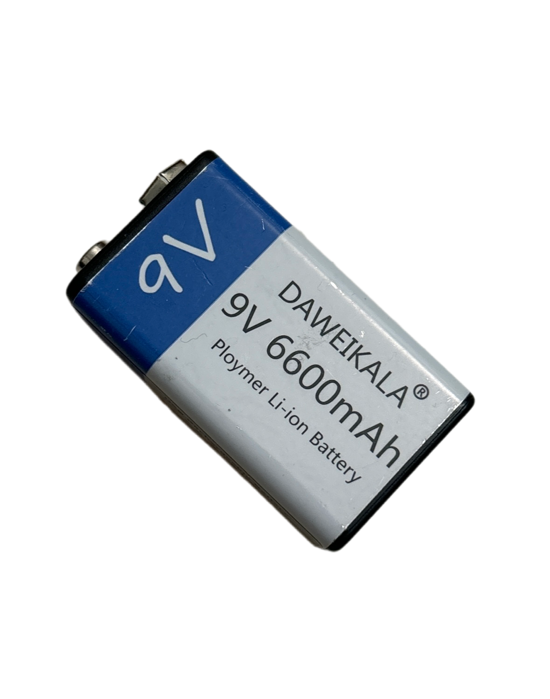
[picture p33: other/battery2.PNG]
  
</picture>
</p> 

2. **Billboard 10,000mAh Power Bank**
   - **Purpose:** Powers the **Raspberry Pi**.  
   - **Reasoning:** The Raspberry Pi demands higher current (via USB 5V) to handle computer vision and advanced processing tasks.  
   - **Advantage:** Provides long runtime with built-in overcharge protection and dual USB outputs, ensuring the Pi has a reliable and safe power source.  
<p align="center">
<picture>
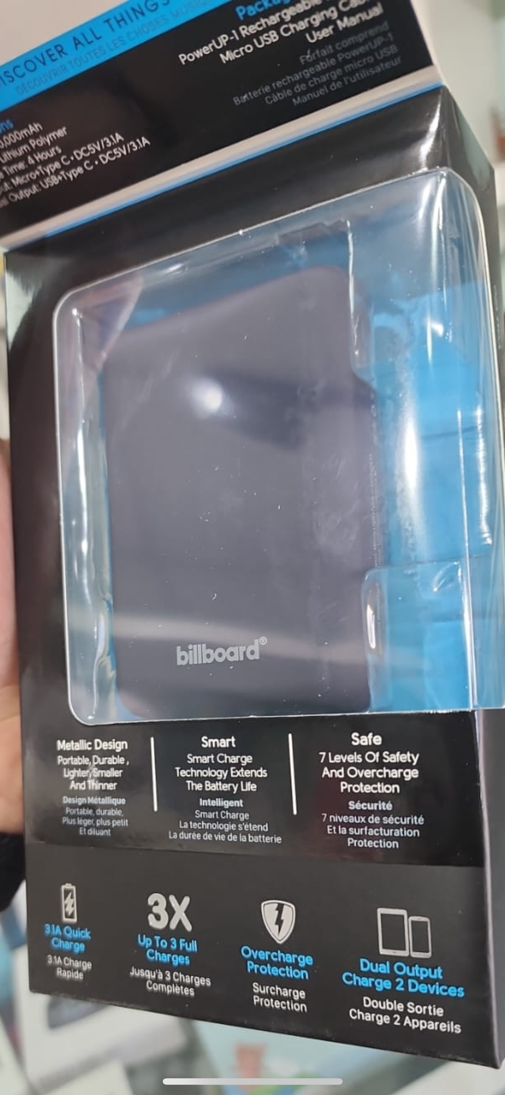
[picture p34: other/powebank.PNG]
  
</picture>
</p>
---

By splitting the power supply:
- The **motors and ESP32** receive dedicated current without fluctuations.  
- The **Raspberry Pi** operates independently, focused on vision and processing.  
This design ensures **stability, efficiency, and longer runtime** for the robot.

---

### 10. Camera:

For vision processing, we equipped the robot with the **Microsoft LifeCam Cinema** USB camera.

- **Resolution:** 720p HD  
- **Interface:** USB 2.0  
- **Purpose:** Provides real-time video input for the **Raspberry Pi**, which runs computer vision algorithms for obstacle detection and navigation.  
- **Reasoning:**  
  - Affordable and easily available.  
  - Compact size, suitable for mounting on the robot chassis.  
  - Reliable driver support on Linux/Raspberry Pi OS.

<p align="center">
<picture>
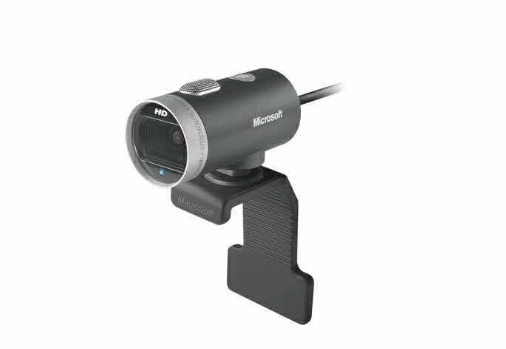
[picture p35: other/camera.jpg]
  
</picture>
</p>

----

## Strategies:

### First Task: Navigation Without Traffic Signs

For the first task of the WRO Future Engineers self-driving car challenge, our robot must navigate a track without traffic signs and complete **three laps**.  

1. **Wall-Following with Ultrasonic Sensors**
   - Two ultrasonic sensors are mounted on the left and right sides of the robot.  
   - On straight sections, the robot uses the sensor readings to maintain a centered position between the track walls.  
   - If one side is closer to the wall, the steering is adjusted to balance the readings and re-center the robot.

2. **Corner Detection**
   - When the robot approaches a corner, one ultrasonic sensor suddenly detects a **much larger distance** (open space).  
   - This change signals that a turn is required.  
   - On detecting a corner:
     - The robot briefly slows down or stops.  
     - The **servo motor** precisely steers the front wheels to execute the turn.  

3. **Lap Counting**
   - Each successful turn is counted as progress along the lap.  
   - After detecting **12 turns**, the robot concludes that **3 laps** have been completed.  
   - The robot then comes to a full stop.

**Key Points**
- **Ultrasonic sensors** ensure continuous wall detection and provide reliable corner identification.  
- **Servo steering** allows accurate maneuvering around corners.  
- **Turn-based lap counting** avoids the need for external markers and ensures consistent lap tracking.

---

### Second Task : Obstacle Avoidance

For the second task of the WRO Future Engineers self-driving car challenge, the robot must navigate a track while avoiding obstacles placed along the way.  

1. **Camera and Raspberry Pi (High-Level Control)**
   - A USB camera connected to the Raspberry Pi continuously captures frames.  
   - Each frame is processed by a **Teachable Machine Lite model** (`model.tflite` with `labels.txt`).  
   - Classification results determine the action:
     - **Red Block** → Raspberry Pi sends `L` (Left) via serial.  
     - **Green Block** → Raspberry Pi sends `R` (Right) via serial.  
     - **No Block / Other** → Raspberry Pi sends `F` (Forward).  
   - The Pi communicates commands to the **ESP32** through serial (TX/RX pins).  

2. **ESP32 and Actuators (Low-Level Control)**
   - The ESP32 interprets the commands from the Raspberry Pi.  
   - **L** → Servo motor steers the front wheels left.  
   - **R** → Servo motor steers the front wheels right.  
   - **F** → Motors continue forward using the H-Bridge driver.  

3. **Ultrasonic Sensors**
   - **Side ultrasonics**: Keep the robot centered on straights and detect corners (same logic as Task 1).  
   - **Front ultrasonic**: Measures distance directly ahead. If an obstacle is too close (e.g., < 15 cm), the robot stops, moves backwards, then avoids the obstacle in the correct way.  

4. **Lap Counting**
   - Just like in Task 1, each successful turn increments a counter.  
   - After **12 turns**, the robot concludes that 3 laps are complete and stops.  

**Key Points**
- **Dual-layer system**:  
  - Raspberry Pi handles **visual recognition and decision-making**.  
  - ESP32 + ultrasonic sensors handle **navigation, obstacle safety, and motor control**.  
- **Fail-safe operation**: If the camera fails to classify, the robot defaults to ultrasonic-based navigation.  
- **Stable execution**: The front ultrasonic ensures the robot never collides while reacting to visual cues.

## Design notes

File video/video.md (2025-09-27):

This is a demo video of our robot moving on the track.

<video src="./moving.mov" width="600" controls></video>

# Robot Demo Video

This is a demo video of our robot moving on the track.

## Local Video
<video src="./moving.mov" width="600" controls></video>
## Youtube Link 
[watch on youtube](https://youtube.com/shorts/H7jsI2t4uU8?si=0EMuis0wYFP-S493)

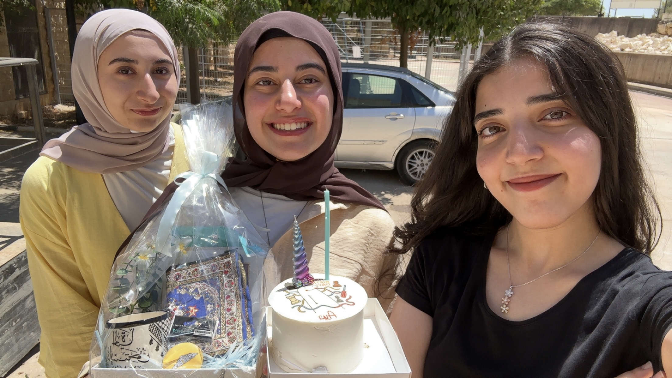
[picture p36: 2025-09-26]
t-photos/FunPicture.jpg

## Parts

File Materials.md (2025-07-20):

## Engineering Material
- Raspberri pi 4
- ESP-WROOM-32
- ESP32 expansion board
- H-bridge
- DC Mototr
- Servo Motor
- Infrared Sensor
- Color Sensor
- ultrasonics : we used 3 ultrasonics 2 on the sides and 1 in the front

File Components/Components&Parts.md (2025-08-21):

# Material
The Material we used to build our robot car
## Raspberry Pi 4
<p align="center">
  Raspberry Pi 4
</p>

- **Processor**: 1.5GHz 64-bit quad-core  
- **RAM**: 8GB LPDDR4  
- **SD card**: 32GB 
- **Ports**: 2 USB 3.0 ports, 2 USB 2.0 ports
- **Operation Voltage** : 5.1V at 3A
- **Dimensions** : 85mm x 56mm x 17mm
- **Connectivity**:  
  - Dual-band Wi-Fi  
  - Bluetooth 5.0  
  - Gigabit Ethernet  
  - USB 3.0

***Purpose*** : The purpose of using the Raspberry Pi 4 was to connect a camera that provides visual input to the system. This input is then processed using machine learning, including image classification and recognition. Moreover, these methods guide the robot car to determine the turning direction based on live information and observations. In addition, the system can make decisions on the spot in a changing environment.

***Selection reason*** : As for the reason for choosing the Raspberry Pi 4, it is due to its easier-to-provide power source and lower power consumption. It is also more compatible when coding and using libraries. and lastly, its accessories are more affordable, and it generates less heat compared to the Raspberry Pi 5.

## ESP32
<p align="center">
  Raspberry Pi 4
</p>

- **Model**: ESP32-WROOM-32 
- **Board**: NodeMCU-ESP32 (ESP32 DEVKITV1)  
- **Chip**: ESP32 (Dual-core Xtensa LX6, up to 240MHz)  
- **Wi-Fi**: 802.11 b/g/n (2.4GHz)  
- **Bluetooth**: v4.2 BR/EDR + BLE  
- **RAM**: 520KB SRAM  
- **Flash**: 4MB (or 16MB, depending on variant)  
- **GPIO Pins**: 38 (including ADC, DAC, UART, SPI, I2C)  
- **USB**: Micro-USB (for power/programming)  
- **Operating Voltage**: 3.3V
- **Dimensions** : 18mm x 25.5mm x 3.1mm

***Purpose*** : its to connect the rest of the robots components, sensors and motors, to ensure their best performance, we programmed the microcontroller using C++, It connects to the Raspberry Pi, which handles image recognition. Based on camera input (red or green obstacle), the Raspberry Pi sends commands to the ESP32, which then executes movement based on the code the esp32 runs, through the connected hardware.

***Selection reason*** : The ESP32 has many captivating and suitable features for our project, it has processing power of Dual-core 32-bit Xtensa CPU, up to 240 MHz, it has both Wi-Fi and Bluetooth (Classic + BLE) built-in, enough memory (520KB) to handle our code and execute it smoothly, has PWM On most GPIOs, its more cost effective, and it has more advanced features.

## Ultrasonic Sensor
<p align="center">
<picture>
  Ultrasonic Sensor
</picture>
</p>

**Model**: HC-SR04
**Voltage:** 5V DC  
**Current:** 15mA  
**Frequency:** 40Hz  
**Max Range:** 4m  
**Min Range:** 2cm  
**Measuring Angle:** 15°  
**Trigger Input:** 10µs TTL pulse  
**Echo Output:** TTL level signal (range proportional)  
**Dimensions:** 45 × 20 × 15 mm  

***Purpose*** : We have adopted a strategy that requires three ultrasonic sensors to be used effectively. Two sensors are placed on the sides, while the third is positioned at the front of the car. The side sensors are responsible for measuring the distance between the car and the walls on each side of the path. They continuously compare the two readings to determine the car’s position. When one of the side sensors detects a distance greater than the other by more than 2 meters, the system will determine that side as the turning direction of the path. As for the third sensor at the front, its main purpose is to measure the distance between the car and any obstacles, which will later be used to decide when the car should start turning at an angle to avoid collisions. It will also measure the distance between the walls of the track and the car, which will be useful—combined with our servomotor and camera in Task 2.

## Infrared Sensor
<p align="center">
<picture>
  Infrared Sensor
</picture>
</p>

- **Model**: TCRT5000  
- **Operating Voltage**: 3.3V – 5V  
- **Current Consumption**: ~18–20 mA  
- **Detection Range**: 2 mm – 15 mm (optimal within 2–10 mm)  
- **Output Signal**: Digital (HIGH/LOW) or Analog (depending on board version)  
- **Detection Type**: Reflective infrared (IR LED + phototransistor)  
- **Wavelength**: ~950 nm (IR emitter)  
- **Response Time**: <1 ms (fast switching)  
- **Adjustable Sensitivity**: Yes (via onboard potentiometer, if available)  
- **Indicator LEDs**: Power and output status  
- **Dimensions (module)**: ~3.2 cm × 1.4 cm (can vary by version)  

***Purpose*** : The purpose of this sensor is to detect short distances between the robot and its surroundings. While it may seem similar to the ultrasonic sensor, its main role is to provide an extra layer of safety to prevent collisions with obstacles or walls. It also helps the robot determine when to move backwards if needed.  

***Selection reason*** : It senses short distances more precisely than the ultrasonic sensor.  

## Color Sensor
<p align="center">
<picture>
  Color Sensor
</picture>
</p>

- **Model**: TCS3200 Color Sensor  
- **Operating Voltage**: 2.7V – 5.5V (typically 5V)  
- **Operating Current**: ~2.5 mA (average)  
- **Output Type**: Frequency (square wave) proportional to light intensity  
- **Sensing Element**: 8×8 array (64 photodiodes):  
  - 16 red filters  
  - 16 green filters  
  - 16 blue filters  
  - 16 clear (no filter)  
- **Selectable Output Frequency Scaling**: 100%, 20%, and 2%  
- **Measurement Range**: Full visible spectrum (RGB + clear)  
- **Response Time**: <100 ms typical  
- **Interface**: Digital output (no ADC needed)  
- **Detection Method**: Measures reflected light intensity of different colors  
- **Module Dimensions**: ~28 mm × 28 mm (may vary by version)  

***Purpose*** : Its main job is to detect either a green or orange line on the mat, which is used to count how many laps the robot car has completed. If it detects 12 orange lines, it means the car has finished 3 laps and should park (the mat has 4 orange lines at each corner, so 4 lines equal one lap). The color sensor also had another role in a different strategy: to determine the direction of the car (clockwise or counterclockwise). This was based on the color of the first line detected, which guided the system to track that color and decide turning direction.  

***Selection reason*** : Provides reliable detection of specific colors, enabling lap counting and alternative navigation strategies.  

---

## H-Bridge
<p align="center">
<picture>
  H-Bridge
</picture>
</p>

- **Voltage**: 5V to 35V  
- **Logic Voltage**: 5V  
- **Continuous Current**: 2A per channel  
- **Peak Current**: 3A per chann
- **Channels**: 2 (dual H-Bridge)  
- **Speed Control**: PWM (ENA/ENB pins)  
- **Direction Control**: IN1, IN2, IN3, IN4  
- **Protection**: Thermal shutdown, current limiting  
- **Flyback Diodes**: Included  

***Purpose*** : The ESP32 cannot directly reverse motor direction, but an H-Bridge enables this through simple digital HIGH/LOW signals. It also supports braking and freewheeling modes, offering finer control. It acts as a power driver, handling higher motor currents safely.  

***Selection reason*** : Without an H-Bridge, a DC motor can only spin one way. The H-Bridge makes motor control safe, programmable, and reliable.  

---

## DC Motor (XY-N20)
<p align="center">
<picture>
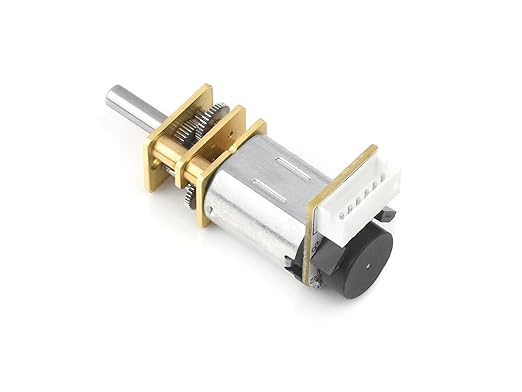
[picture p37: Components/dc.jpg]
XY-N20 DC Gear Motor
  
</picture>
</p>

- **Model**: XY-N20 DC Gear Motor with Magnetic (Hall) Encoder  
- **Rated Voltage**: 12 V DC  
- **No-load Speed**: ~200 RPM  
- **No-load Startup Voltage**: ~3 V (max)  
- **No-load Current**: ~0.1 A (max)  
- **Locked-rotor (Stall) Torque**: ≥ 1.2 kg·cm  
- **Locked-rotor (Stall) Current**: ≥ 1.1 A  
- **Encoder Type**: AB dual-phase incremental magnetic Hall encoder  
- **Encoder Resolution**: Basic 7 PPR × 150 gear ratio = ~1050 PPR  
- **Encoder Power Supply**: 3.3 V or 5 V (with internal pull-up)  
- **Response Frequency**: Up to ~100 kHz  
- **Gearbox**: All-metal, high-precision reduction gearbox  
- **Connector**: L-shaped 6-pin (for motor power and encoder signals)  
- **Rotation**: Reversible (via polarity swap)  

***Purpose*** : Provides both motion and precise feedback for the robot’s navigation. The built-in encoder enables accurate speed or position sensing, improving control over direction and obstacle avoidance.

***Selection Reason*** : Combines durable all-metal gearing with integrated encoder feedback. This enhances both reliability and accuracy, making it ideal for robotics applications needing lightweight yet precise actuators.

---

## Servo Motor
<p align="center">
<picture>
  Servo Motor
</picture>
</p>

- **Model**:DCGM-N20-12V-EN-200RPM
- **Voltage**: 4.8V to 6V  
- **Operating Current**: ~100 mA to 250 mA (under load)  
- **Stall Torque**: 1.8 kg·cm at 4.8V  
- **Speed**: ~0.1 sec/60° at 4.8V  
- **Rotation Range**: 0° to ~180° (limited by internal stops)  
- **Control Signal**: PWM (50 Hz, 1–2 ms pulse width)  
- **Motor Type**: Brushed DC motor with control circuitry and feedback  
- **Weight**: ~9 g  
- **Dimensions**: 22.8 × 12.2 × 29.5 mm  
- **Gear Type**: Plastic gears  
- **Shaft Type**: Spline (21 teeth)  
- **Connector**: 3-pin (Signal, VCC, GND)  

***Purpose*** : Used in the robot car’s steering mechanism. In Task 2, it worked with the camera and Teachable Machine to avoid obstacles dynamically by adjusting angles gradually. In Task 1, it turned 90° at track edges with ultrasonic input to keep the car aligned.  

***Selection reason*** : Compact, affordable, easy to control, and accurate for 0°–180° rotation, making it ideal for steering.  

---

## ESP32 Expansion Board
<p align="center">
<picture>
  ESP32 Expansion Board
</picture>
</p>

- **Microcontroller**: ESP32 (dual-core, 240 MHz)  
- **Connectivity**: Wi-Fi + Bluetooth  
- **Operating Voltage**: 3.3V  
- **Programming**: Arduino IDE or MicroPython  
- **USB**: For power and programming (usually Micro-USB)  

***Purpose*** : Acts as the main controller for connecting sensors, processing inputs, and controlling outputs such as LEDs and motors.  

***Selection reason*** : Supports wireless communication, IoT applications, and runs code directly (Arduino/MicroPython). Flexible, powerful, and easy to integrate.  

---

## Camera
<p align="center">
<picture>
  Camera
</picture>
</p>

***Specification*** : (to be filled)  

***Purpose*** : Provides real-time visual input for machine learning–based navigation and obstacle detection.  

***Selection reason*** : Essential for implementing image recognition and guiding the robot’s decision-making system.  

---

## Teachable Machine
<p align="center">
<picture>
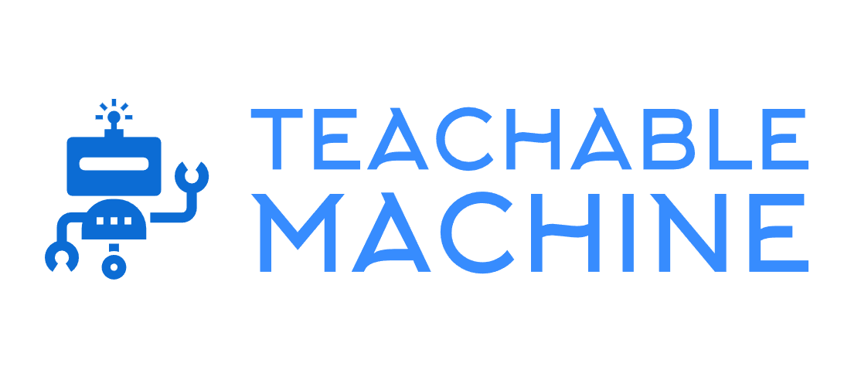
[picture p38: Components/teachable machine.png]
Teachable Machine
  
</picture>
</p>

***Purpose*** : Allowed the team to quickly train an image classification model without complex coding. The model was exported as TensorFlow Lite and deployed to the device for real-time object recognition, integrating machine learning into the robot’s decision-making system.  

***Selection reason*** : Simplified ML integration, reduced development time, and provided accessible tools for fast prototyping.

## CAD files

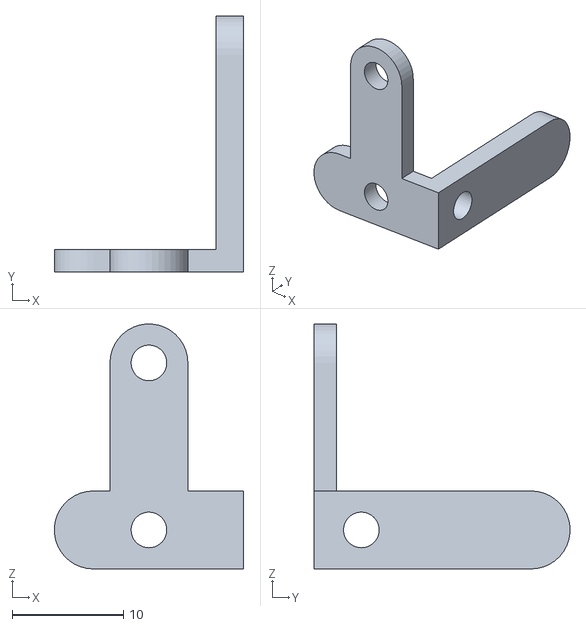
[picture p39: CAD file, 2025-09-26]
models/Part1better.STL
17.0 x 23.0 x 22.0

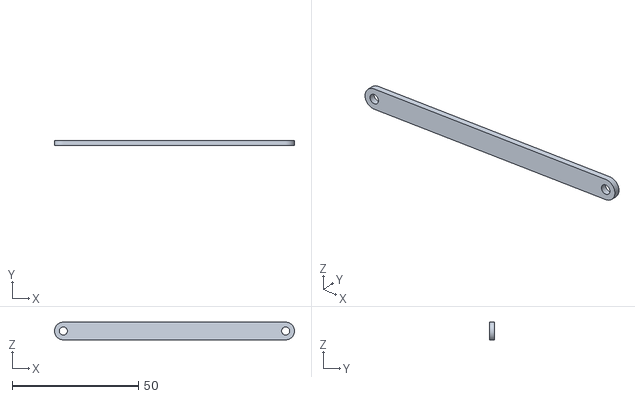
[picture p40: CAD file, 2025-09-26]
models/Part3.STL
95.0 x 2.00 x 7.00

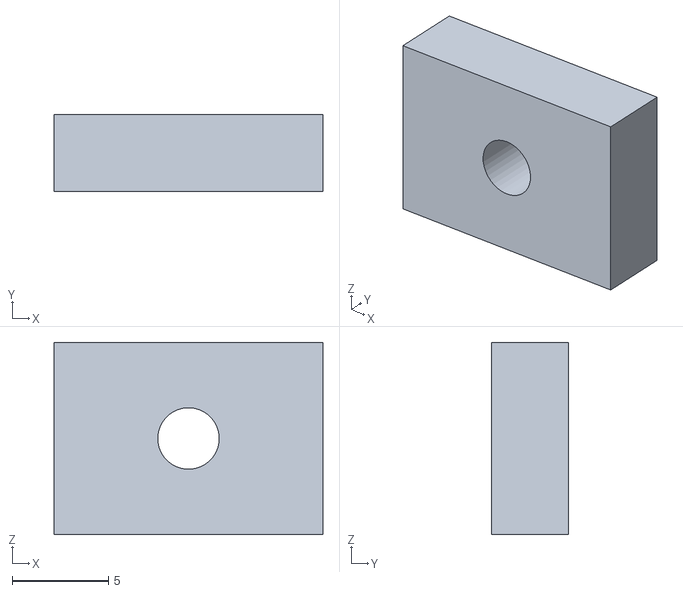
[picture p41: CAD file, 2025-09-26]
models/Part5.STL
14.0 x 4.00 x 10.0

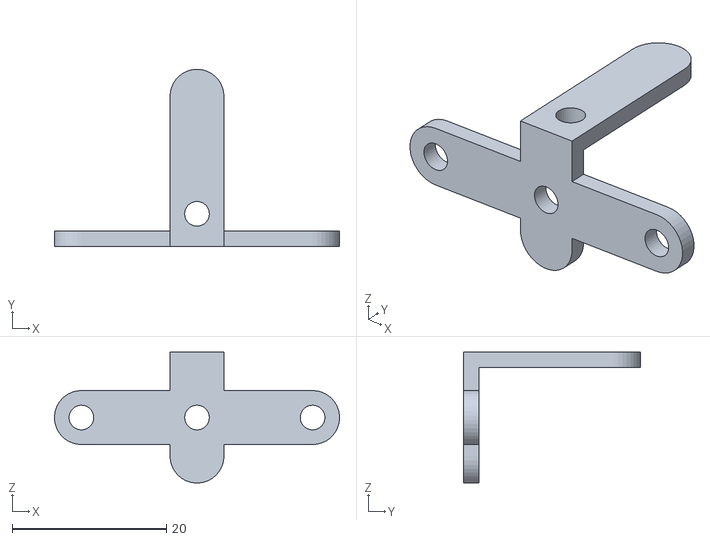
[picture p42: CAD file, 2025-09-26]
models/Part2better.STL
37.0 x 23.0 x 17.0

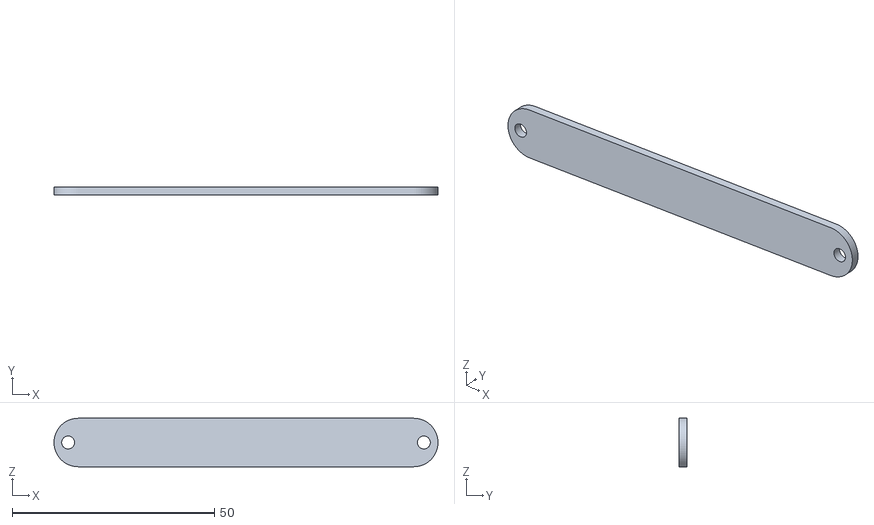
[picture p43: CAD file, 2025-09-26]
models/Part4.STL
95.0 x 2.00 x 12.0

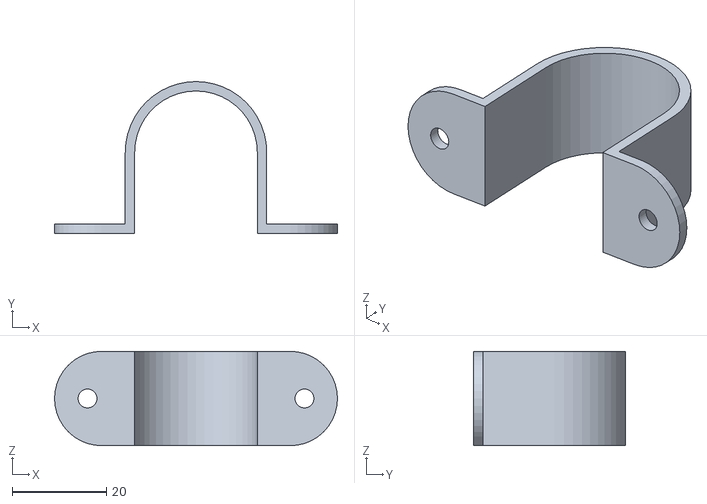
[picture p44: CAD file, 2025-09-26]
models/NewMotorPiece.stl
60.0 x 32.2 x 20.0

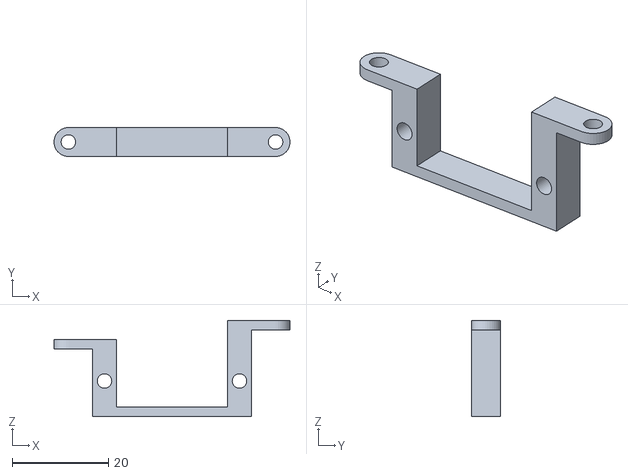
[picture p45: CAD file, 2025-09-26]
models/servo-motor-piece.stl
49.0 x 6.00 x 20.0

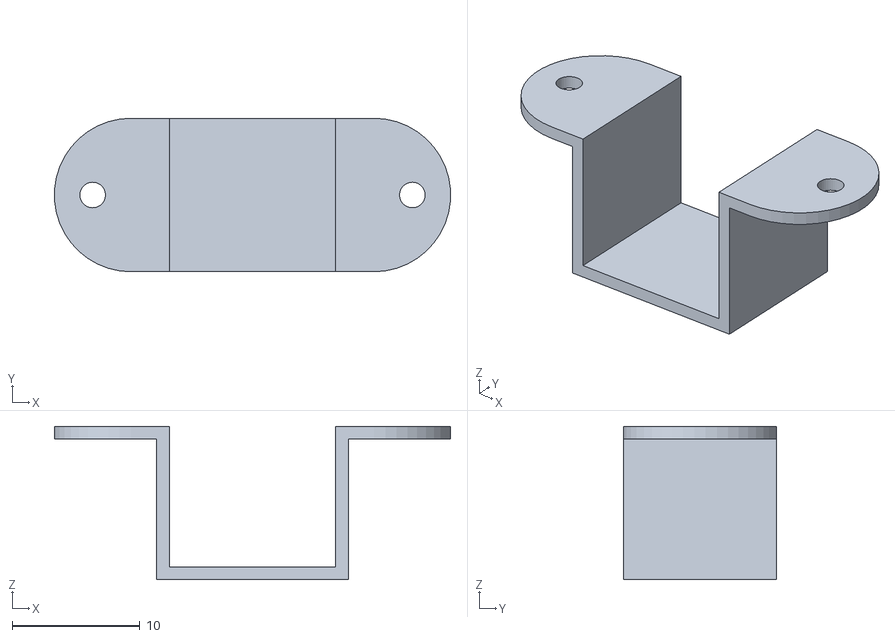
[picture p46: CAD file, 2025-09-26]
models/motor-par1t.stl
31.0 x 12.0 x 12.0

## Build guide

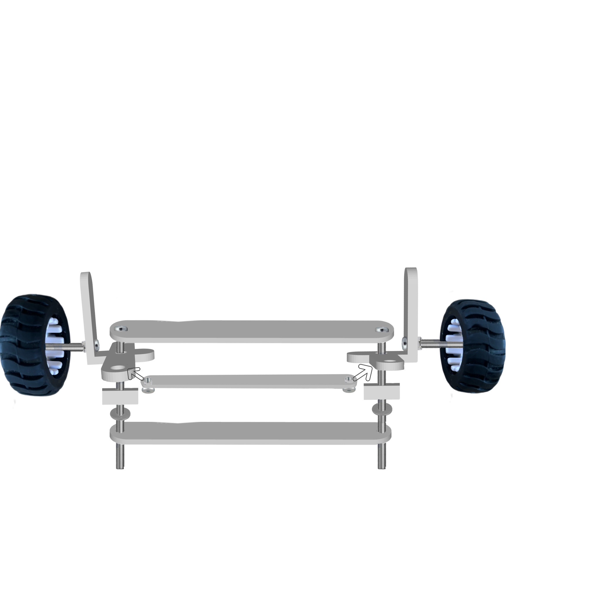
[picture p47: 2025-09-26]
other/steeringsetup.JPG

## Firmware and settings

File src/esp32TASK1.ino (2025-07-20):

#include <Arduino.h>
#include <Servo.h>

// --- Pin Definitions 

// Ultrasonic Left
const int ULTRASONIC_LEFT_ECHO_PIN = 35;
const int ULTRASONIC_LEFT_TRIG_PIN = 25;

// Ultrasonic Right
const int ULTRASONIC_RIGHT_ECHO_PIN = 13;
const int ULTRASONIC_RIGHT_TRIG_PIN = 12;

// Infrared Sensor
const int INFRARED_SENSOR_PIN = 14;

// Servo Motor (Front Steering)
const int SERVO_PIN = 21;

// DC Motor (Rear Wheels) - H-bridge Control (L298N-like setup)
// Selected from your list: D27, D26, D25, D33, D23, D22.
// Using D27 and D26 for direction, and D33 for PWM speed control.
const int DC_MOTOR_IN1_PIN = 27;
const int DC_MOTOR_IN2_PIN = 26;
const int DC_MOTOR_ENABLE_PIN = 33; // This pin is used for PWM

// Encoder for DC Motor (Rear Wheels)
// D19 for Channel A (interrupt), D18 for Channel B.
const int ENCODER_DC_MOTOR_A_PIN = 19;
const int ENCODER_DC_MOTOR_B_PIN = 18;

// Color Sensor (TCS3200/TCS34725)
const int COLOR_SENSOR_OE_PIN = 17;
const int COLOR_SENSOR_S0_PIN = 4;
const int COLOR_SENSOR_S1_PIN = 16;
const int COLOR_SENSOR_S2_PIN = 21;  // Moved from D15
const int COLOR_SENSOR_S3_PIN = 22;  // Moved from D22
const int COLOR_SENSOR_OUT_PIN = 15; // Moved from D2

// --- Constants ---
#define US_SOUND_SPEED_CM_PER_US 0.0343 //to calculate distance from ultrasonic
#define MAX_DISTANCE_CM 200 

// Motor Speed
const int FORWARD_SPEED = 150; // PWM value (0-255) for forward movement dc motor
const int TURN_SPEED = 100;    // PWM value for turning if needed

// Servo Angles
const int SERVO_STRAIGHT = 90; // Angle for straight
const int SERVO_TURN_LEFT = 0; // Angle for full left (adjust if your servo range is different)
const int SERVO_TURN_RIGHT = 180; // Angle for full right

// Distance Thresholds for Corner Detection
const int CORNER_DIFFERENCE_THRESHOLD_CM = 50; // Difference in ultrasonic readings to detect a corner
const int CORNER_INNER_SIDE_LARGE_DISTANCE_CM = 100; // Threshold for the inner side ultrasonic reading

// Color Sensor Thresholds (These are initial guesses based on RGB, YOU MUST CALIBRATE)
// Assuming your sensor outputs 'higher' values for 'less' of a color (e.g., lower red reading if much red is present)
// These thresholds will likely need to be adjusted based on your sensor's actual output range and lighting.
const int COLOR_THRESHOLD_BLUE_R = 150; // Lower red than green/blue
const int COLOR_THRESHOLD_BLUE_G = 150; // Lower green than blue
const int COLOR_THRESHOLD_BLUE_B = 50;  // Significantly higher blue

const int COLOR_THRESHOLD_ORANGE_R = 50;  // Significantly higher red
const int COLOR_THRESHOLD_ORANGE_G = 150; // Lower green than red
const int COLOR_THRESHOLD_ORANGE_B = 150; // Lower blue than red

const int MAX_COLOR_COUNT = 12; // Robot stops when this count is reached

// --- Global Variables ---
Servo frontServo;

volatile long encoderDcMotorPulses = 0; // Use volatile for variables modified in ISR

int colorCounter = 0;
bool lastColorWasBlue = false; // To track consecutive colors

// --- Function Prototypes ---
long readUltrasonicDistance(int trigPin, int echoPin);
void setMotorSpeed(int speed);
void setMotorDirection(bool forward); // true for forward, false for backward
void stopMotor();
void rotateServoSlowly(int targetAngle, int delayMs);
void readColorSensor(int &r, int &g, int &b);
void checkAndCountColor();

// Encoder Interrupt Service Routine
void IRAM_ATTR handleDcMotorEncoderA();

// --- Setup ---
void setup() {
    Serial.begin(115200);
    Serial.println("Robot starting up...");

    // Ultrasonic Pins
    pinMode(ULTRASONIC_LEFT_TRIG_PIN, OUTPUT);
    pinMode(ULTRASONIC_LEFT_ECHO_PIN, INPUT);
    pinMode(ULTRASONIC_RIGHT_TRIG_PIN, OUTPUT);
    pinMode(ULTRASONIC_RIGHT_ECHO_PIN, INPUT);

    // Infrared Sensor
    pinMode(INFRARED_SENSOR_PIN, INPUT);

    // Servo Motor
    frontServo.attach(SERVO_PIN);
    frontServo.write(SERVO_STRAIGHT); // Start straight

    // DC Motor H-bridge Pins
    pinMode(DC_MOTOR_IN1_PIN, OUTPUT);
    pinMode(DC_MOTOR_IN2_PIN, OUTPUT);
    pinMode(DC_MOTOR_ENABLE_PIN, OUTPUT);
    ledcSetup(0, 5000, 8); // Setup PWM channel 0, 5kHz frequency, 8-bit resolution (0-255)
    ledcAttachPin(DC_MOTOR_ENABLE_PIN, 0); // Attach pin to PWM channel

    // Encoder Pins - Setup interrupts for quadrature
    pinMode(ENCODER_DC_MOTOR_A_PIN, INPUT_PULLUP);
    pinMode(ENCODER_DC_MOTOR_B_PIN, INPUT_PULLUP);
    // Attach interrupt to Channel A, triggering on CHANGE (both rising and falling edges)
    // to detect quadrature signals for both speed and direction.
    attachInterrupt(digitalPinToInterrupt(ENCODER_DC_MOTOR_A_PIN), handleDcMotorEncoderA, CHANGE);

    // Color Sensor Pins
    pinMode(COLOR_SENSOR_OE_PIN, OUTPUT);
    pinMode(COLOR_SENSOR_S0_PIN, OUTPUT);
    pinMode(COLOR_SENSOR_S1_PIN, OUTPUT);
    pinMode(COLOR_SENSOR_S2_PIN, OUTPUT);
    pinMode(COLOR_SENSOR_S3_PIN, OUTPUT);
    pinMode(COLOR_SENSOR_OUT_PIN, INPUT);

    digitalWrite(COLOR_SENSOR_OE_PIN, LOW); // Enable the color sensor
    // Set frequency scaling for TCS3200/TCS34725. HIGH, HIGH is usually 100%
    digitalWrite(COLOR_SENSOR_S0_PIN, HIGH);
    digitalWrite(COLOR_SENSOR_S1_PIN, HIGH);
}

// --- Loop ---
void loop() {
    if (colorCounter >= MAX_COLOR_COUNT) {
        stopMotor();
        frontServo.write(SERVO_STRAIGHT);
        Serial.println("Color count reached! Robot stopped.");
        while (true) {
            // Robot stops completely.
            delay(100);
        }
    }

    long leftDistance = readUltrasonicDistance(ULTRASONIC_LEFT_TRIG_PIN, ULTRASONIC_LEFT_ECHO_PIN);
    long rightDistance = readUltrasonicDistance(ULTRASONIC_RIGHT_TRIG_PIN, ULTRASONIC_RIGHT_ECHO_PIN);

    Serial.print("Left Dist: "); Serial.print(leftDistance); Serial.print(" cm, ");
    Serial.print("Right Dist: "); Serial.print(rightDistance); Serial.print(" cm, ");
    Serial.print("Encoder Pulses: "); Serial.println(encoderDcMotorPulses);

    // Check for corner detection
    if (abs(leftDistance - rightDistance) > CORNER_DIFFERENCE_THRESHOLD_CM) {
        if (leftDistance > CORNER_INNER_SIDE_LARGE_DISTANCE_CM) {
            // Likely a left turn (left side is "open" - inner side of corner)
            Serial.println("Corner detected! Turning left slowly.");
            stopMotor();
            rotateServoSlowly(SERVO_TURN_LEFT, 50);
            delay(100);
            delay(2000); // Stay in corner for 2 seconds to allow adjustment/color reading
            checkAndCountColor(); // Read color while adjusting/at corner
            frontServo.write(SERVO_STRAIGHT); // Straighten wheels for next section
            delay(500); // Allow servo to reset
            setMotorDirection(true); // Ensure direction is forward
            setMotorSpeed(FORWARD_SPEED); // Move fast again
        } else if (rightDistance > CORNER_INNER_SIDE_LARGE_DISTANCE_CM) {
            // Likely a right turn (right side is "open" - inner side of corner)
            Serial.println("Corner detected! Turning right slowly.");
            stopMotor();
            rotateServoSlowly(SERVO_TURN_RIGHT, 50);
            delay(100);
            delay(2000); // Stay in corner for 2 seconds
            checkAndCountColor();
            frontServo.write(SERVO_STRAIGHT);
            delay(500);
            setMotorDirection(true); // Ensure direction is forward
            setMotorSpeed(FORWARD_SPEED);
        }
    } else {
        // No corner detected, keep moving forward
        Serial.println("Moving forward...");
        setMotorDirection(true); // Always ensure forward direction
        setMotorSpeed(FORWARD_SPEED);
        frontServo.write(SERVO_STRAIGHT); // Ensure wheels are straight
    }

    // You can add more frequent color checking here if desired, but be mindful of timing.
    // For now, it's primarily checked during corner adjustments.
    /*
    if (millis() % 500 == 0) {
        checkAndCountColor();
    }
    */

    delay(50);
}

// --- Function Implementations ---

// Ultrasonic Sensor Reading
long readUltrasonicDistance(int trigPin, int echoPin) {
    digitalWrite(trigPin, LOW);
    delayMicroseconds(2);
    digitalWrite(trigPin, HIGH);
    delayMicroseconds(10);
    digitalWrite(trigPin, LOW);
    long duration = pulseIn(echoPin, HIGH, 30000); // Timeout after 30ms (max distance approx 5m)
    if (duration == 0) return MAX_DISTANCE_CM; // If no echo, assume max distance
    long distanceCm = duration * US_SOUND_SPEED_CM_PER_US / 2;
    return min(distanceCm, (long)MAX_DISTANCE_CM); // Cap at max distance
}

// DC Motor Control
void setMotorSpeed(int speed) {
    if (speed > 255) speed = 255;
    if (speed < 0) speed = 0;
    ledcWrite(0, speed); // Use PWM channel 0
    // Serial.print("Motor speed set to: "); Serial.println(speed); // Uncomment for more frequent debug output
}

void setMotorDirection(bool forward) {
    if (forward) {
        digitalWrite(DC_MOTOR_IN1_PIN, HIGH);
        digitalWrite(DC_MOTOR_IN2_PIN, LOW);
    } else { // Reverse
        digitalWrite(DC_MOTOR_IN1_PIN, LOW);
        digitalWrite(DC_MOTOR_IN2_PIN, HIGH);
    }
}

void stopMotor() {
    setMotorSpeed(0);
    digitalWrite(DC_MOTOR_IN1_PIN, LOW);
    digitalWrite(DC_MOTOR_IN2_PIN, LOW);
    Serial.println("Motor stopped.");
}

// Servo Motor Slow Rotation
void rotateServoSlowly(int targetAngle, int delayMs) {
    int currentAngle = frontServo.read();
    Serial.print("Rotating servo from "); Serial.print(currentAngle); Serial.print(" to "); Serial.println(targetAngle);

    if (targetAngle > currentAngle) {
        for (int angle = currentAngle; angle <= targetAngle; angle++) {
            frontServo.write(angle);
            delay(delayMs);
        }
    } else if (targetAngle < currentAngle) {
        for (int angle = currentAngle; angle >= targetAngle; angle--) {
            frontServo.write(angle);
            delay(delayMs);
        }
    }
    Serial.println("Servo rotation complete.");
}

// Color Sensor Reading (TCS3200/TCS34725 common logic)
void readColorSensor(int &r, int &g, int &b) {
    // Set sensor to read RED filter
    digitalWrite(COLOR_SENSOR_S2_PIN, LOW);
    digitalWrite(COLOR_SENSOR_S3_PIN, LOW);
    r = pulseIn(COLOR_SENSOR_OUT_PIN, HIGH, 100000); // Measure duration of HIGH pulse (inverse of frequency)
    if (r == 0) r = 65535; // Handle timeout/no pulse
    r = map(r, 0, 65535, 255, 0); // Invert duration and scale to 0-255 (Higher frequency = shorter pulse = more of that color)

    // Set sensor to read GREEN filter
    digitalWrite(COLOR_SENSOR_S2_PIN, HIGH);
    digitalWrite(COLOR_SENSOR_S3_PIN, HIGH);
    g = pulseIn(COLOR_SENSOR_OUT_PIN, HIGH, 100000);
    if (g == 0) g = 65535;
    g = map(g, 0, 65535, 255, 0);

    // Set sensor to read BLUE filter
    digitalWrite(COLOR_SENSOR_S2_PIN, LOW);
    digitalWrite(COLOR_SENSOR_S3_PIN, HIGH);
    b = pulseIn(COLOR_SENSOR_OUT_PIN, HIGH, 100000);
    if (b == 0) b = 65535;
    b = map(b, 0, 65535, 255, 0);

    Serial.print("Color R: "); Serial.print(r);
    Serial.print(" G: "); Serial.print(g);
    Serial.print(" B: "); Serial.println(b);
}

void checkAndCountColor() {
    int red, green, blue;
    readColorSensor(red, green, blue);

    bool currentColorIsBlue = false;
    bool currentColorIsOrange = false;

    // Basic color detection. YOU MUST CALIBRATE THESE THRESHOLDS with your actual sensor readings.
    // The logic below is based on the idea that for a color, its dominant component is high, others are low.
    // For Blue: Blue is high, Red & Green are low
    // For Orange (approx. Red/Yellow): Red is high, Green is moderate, Blue is low
    if (blue > COLOR_THRESHOLD_BLUE_B && red < COLOR_THRESHOLD_BLUE_R && green < COLOR_THRESHOLD_BLUE_G) {
        currentColorIsBlue = true;
    } else if (red > COLOR_THRESHOLD_ORANGE_R && green > COLOR_THRESHOLD_ORANGE_G && blue < COLOR_THRESHOLD_ORANGE_B) {
        currentColorIsOrange = true;
    }

    if (currentColorIsBlue) {
        Serial.println("Detected Blue!");
        if (!lastColorWasBlue) { // Only increment if the color changed from non-blue to blue
            colorCounter++;
            Serial.print("Color Counter: "); Serial.println(colorCounter);
            lastColorWasBlue = true;
        }
    } else if (currentColorIsOrange) {
        Serial.println("Detected Orange!");
        if (lastColorWasBlue) { // Only increment if the color changed from blue to orange (or vice-versa for orange detection logic)
            colorCounter++;
            Serial.print("Color Counter: "); Serial.println(colorCounter);
            lastColorWasBlue = false; // Reset for next color detection
        }
    } else {
        Serial.println("Detected Unknown Color. Resetting last color tracking.");
        // If you want to ensure distinct blue/orange detection,
        // you might reset lastColorWasBlue to a neutral state if an unknown color is read.
        // This prevents double-counting if the sensor briefly loses track.
        // For simplicity, I'm setting it to false which implies "not blue"
        lastColorWasBlue = false;
    }
}

// Encoder ISR for DC Motor (Quadrature)
// This ISR is called on any CHANGE (rising or falling edge) of Encoder A.
// It checks the state of Encoder B to determine the direction of rotation.
void IRAM_ATTR handleDcMotorEncoderA() {
    // Read the current state of both encoder pins
    int encoderAState = digitalRead(ENCODER_DC_MOTOR_A_PIN);
    int encoderBState = digitalRead(ENCODER_DC_MOTOR_B_PIN);

    // If A leads B, it's one direction; if B leads A, it's the other direction.
    // This simplified logic assumes standard quadrature encoder behavior.
    if (encoderAState == HIGH) { // If A is rising edge
        if (encoderBState == LOW) { // B is low, then A leads B (e.g., forward)
            encoderDcMotorPulses++;
        } else { // B is high, then B leads A (e.g., reverse)
            encoderDcMotorPulses--;
        }
    } else { // If A is falling edge
        if (encoderBState == HIGH) { // B is high, then A leads B (e.g., forward)
            encoderDcMotorPulses++;
        } else { // B is low, then B leads A (e.g., reverse)
            encoderDcMotorPulses--;
        }
    }
}

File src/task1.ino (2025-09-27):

#include <ESP32Servo.h>

// Servo setup
Servo myServo;
int servoPin = 32;

// Motor driver pins
const int IN1 = 4;
const int IN2 = 18;
const int EN  = 21;

// Ultrasonic sensor pins
const int trigLeft = 25;
const int echoLeft = 26;
const int trigRight = 27;
const int echoRight = 14;

// Lap counter
int lapCounter = 0;

// Function to measure distance
long readUltrasonic(int trigPin, int echoPin) {
  digitalWrite(trigPin, LOW);
  delayMicroseconds(2);
  digitalWrite(trigPin, HIGH);
  delayMicroseconds(10);
  digitalWrite(trigPin, LOW);

  long duration = pulseIn(echoPin, HIGH, 30000); // timeout 30ms
  long distance = duration * 0.034 / 2;
  return distance; // in cm
}

void setup() {
  // Servo
  myServo.attach(servoPin);
  myServo.write(55);  // center steering
  delay(500);

  // Motor pins
  pinMode(IN1, OUTPUT);
  pinMode(IN2, OUTPUT);
  pinMode(EN, OUTPUT);

  // Set motor forward
  digitalWrite(IN1, HIGH);
  digitalWrite(IN2, LOW);
  digitalWrite(EN, HIGH);

  // Ultrasonic pins
  pinMode(trigLeft, OUTPUT);
  pinMode(echoLeft, INPUT);
  pinMode(trigRight, OUTPUT);
  pinMode(echoRight, INPUT);

  Serial.begin(115200);
}

void loop() {
  long distLeft = readUltrasonic(trigLeft, echoLeft);
  long distRight = readUltrasonic(trigRight, echoRight);

  Serial.print("Left: "); Serial.print(distLeft);
  Serial.print(" cm  Right: "); Serial.print(distRight);
  Serial.print(" cm  Laps: "); Serial.println(lapCounter);

  // Check for corner (open space >70 cm on one side)
  if (distLeft > 70 && distRight < 70) {
    myServo.write(100); // steer right
    delay(800);
    myServo.write(55);  // straighten
    lapCounter++;
  } 
  else if (distRight > 70 && distLeft < 70) {
    myServo.write(10);  // steer left
    delay(800);
    myServo.write(55);
    lapCounter++;
  }
  else {
    myServo.write(55);  // keep straight
  }

  // Stop after 12 turns (3 laps)
  if (lapCounter >= 12) {
    digitalWrite(EN, LOW);  // stop motor
    while (true);           // freeze program
  }
}

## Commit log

2025-07-19 Add files via upload
    second attempt on task 1 using esp32 and C++ instead of Raspberry Pi and Python
2025-07-19 Update 1sttask.py
    no longer using Python; instead, we are switch to C++
    [1sttask.py]
2025-07-19 Update 2ndtask.py
    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
    [2ndtask.py]
2025-07-20 Update esp32TASK1.ino
    fixed pins
    [esp32TASK1.ino]
2025-07-21 Create video raspberry
2025-07-21 Create Material
2025-07-21 Update and rename Material to Material.md
2025-08-21 Update and rename Material.md to Components&Parts.md
2025-09-24 Add other folder with chassis photo
2025-09-24 Add front wheel image
2025-09-24 Add bearing and wobbling images to other folder
2025-09-26 Add wheel images to other folder
2025-09-26 Add tractor and rear wheels images
2025-09-26 Add all steering component images
2025-09-26 Add spacer and steering mount bracket images
2025-09-26 Add old gear and motor horn images for gearbox documentation
2025-09-26 Add new gear model images
2025-09-26 Add 3D model files for motor and parts
    [NewMotorPiece.stl, motor-par1t.stl, servo-motor-piece.stl]
2025-09-26 Add remaining 3D model STL files
    [Part1better.STL, Part2better.STL, Part3.STL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]
2025-09-27 Add Raspberry Pi and ESP32 code for Task 2
2025-09-27 Add camera, DC motor, and powerbank images to other folder
2025-09-27 Add battery2.PNG to other folder
